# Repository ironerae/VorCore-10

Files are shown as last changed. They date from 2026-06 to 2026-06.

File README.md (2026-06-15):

VorCore 10 Custom CoreXY Gantry Mounts

# VorCore 10: Custom CoreXY Gantry Mounts

VorCore 10 is a custom-designed, open-source CoreXY kinematic mounting system. It bridges the gap between the heavy-duty front-motor layout of the SolidCore and the clean, stacked belt routing made popular by Voron designs.

Optimized and tested for a large, rigid 1000x1000x500mm build volume, this system is built entirely around wider 10mm GT2 belts to handle aggressive accelerations without stretching or skipping.

## Design Lineage & Features

- **SolidCore Inspiration:** X and Y stepper motors are front-mounted, pushing the center of gravity forward and freeing up space at the rear of the machine.
- **Voron-Style Routing:** The belts route across the front of the X-axis extrusion in a stacked configuration, ensuring clean, parallel belt paths rather than looping behind the starting belt.
- **Heavy-Duty 10mm Belts:** Dimensioned strictly for 10mm GT2 belts and matching hardware to eliminate belt stretch on high-speed setups.

## The Kinematic System & Belt Routing

The VorCore 10 system utilizes standard CoreXY kinematics for its belt routing, making it familiar and straightforward to configure. The mounting system consists of four purpose-built modules designed for easy printing, assembly, and maintenance. _(Note: The Front, Center, and Back modules are required in pairs—one set for the left gantry and one set for the right.)_

CoreXY-Kinematics

1. **Front (Motor Mount):** Rigidly holds the NEMA 17 stepper motors in the front corners.
2. **Center (Extrusion Clamp):** Securely grips the X-axis extrusion and maintains perfect alignment for the front-stacked belt path.
3. **Back (Idler Mount):** Houses the rear idler pulleys to return the belts through the kinematic path.
4. **Print Head Belt Adapter:** The crucial anchoring point that cleanly terminates the 10mm stacked belts at the toolhead, ensuring perfect parallel alignment with the X-axis.

## Bill of Materials (BOM)

Below is the total hardware required to build the complete X/Y gantry system.

**Front (Motor Mounts - Left & Right Pair)**

- 12x M3x8 bolts (6 per side)
- 2x 10mm Motor Pulley (1 per side)

**Center (Extrusion Clamps - Left & Right Pair)**

- 4x M5x8 bolts (2 per side, for attaching to 20mm V-Slot Gantry Plate)
- 4x M5x25 bolts (2 per side, for the idlers)
- 4x M3x8 bolts (2 per side, for attaching to the extrusion)
- 2x 10mm GT2 Idlers with teeth (1 per side)
- 2x 10mm GT2 Idlers without teeth / smooth (1 per side)

**Back (Idler Mounts - Left & Right Pair)**

- 2x M5x40 bolts (1 per side, for the idler stack)
- 4x 10mm GT2 Idlers with teeth (2 per side)

**Print Head Belt Adapter (Single Unit)**

- 2x M5x8 bolts (for attaching to 20mm V-Slot Gantry Plate)
- _Note: The adapter includes extra bolt slots for mounting a BLTouch, or other custom toolhead accessories. Feel free to explore and modify!_

## CAD & Source Files

This project was designed entirely in Onshape. To make modifications, adjust for different extrusion profiles, or tweak hole tolerances, you can copy the public workspace directly:

- **[Link to Public Onshape Document](https://cad.onshape.com/documents/c695cb2f7fbb45d5485f2701/w/7bdce7ef937412e146022feb/e/c0170e9e5d0967ed7b441d22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)**

For users who just want to print and assemble, the exported STLs and high-resolution STEP files are included in the `files` directory.

## Recommended Print Settings

To ensure the mounts have the rigidity required to handle 10mm belt tension and high accelerations, please follow these minimum printing guidelines:

- **Material:** ABS, ASA, or PC (PETG can work, but avoid PLA as it will creep under belt tension and motor heat)
- **Wall Loops / Perimeters:** 4
- **Top / Bottom Shells:** 5
- **Infill:** 40% (Grid, Gyroid, or Honeycomb)
- **Layer Height:** 0.2mm

## License

This project is fully open-source. Feel free to download, modify, remix, and share your own upgrades!

---

_VorCore 10 by ironerae_

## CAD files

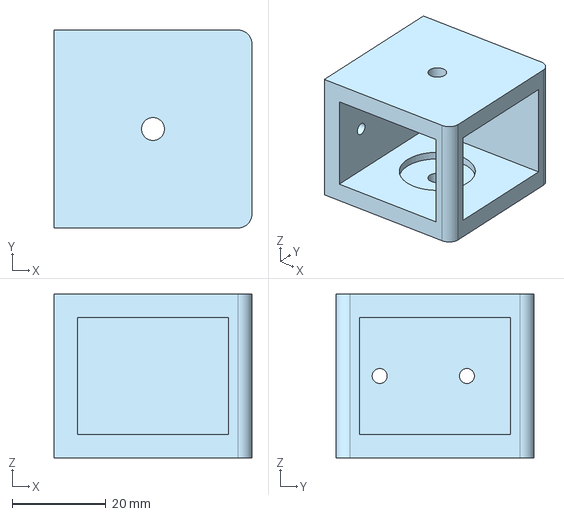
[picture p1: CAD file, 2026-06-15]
files/step/Back (Idler Mount).step
42.3 x 42.3 x 35.0 mm

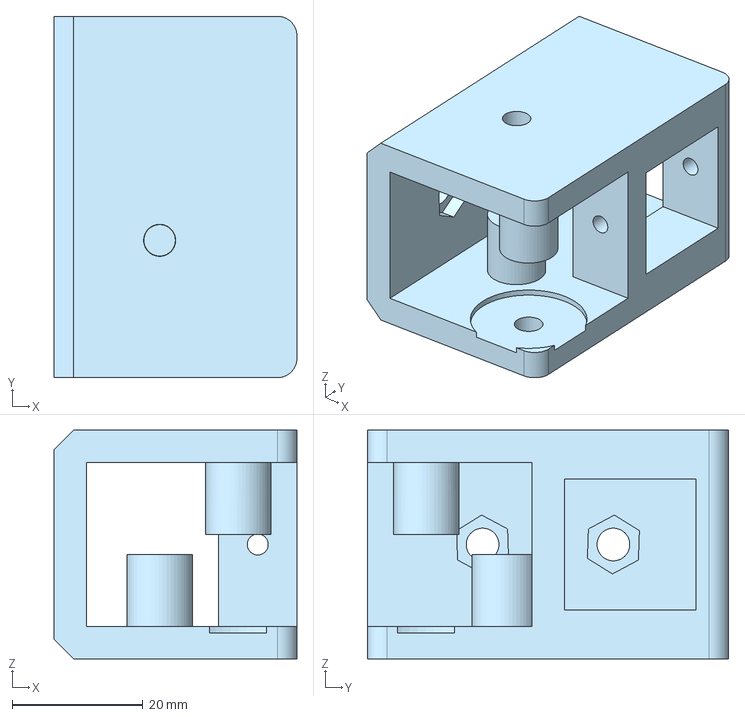
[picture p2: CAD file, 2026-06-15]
files/step/Center (Extrusion Clamp).step
37.1 x 55.2 x 35.0 mm

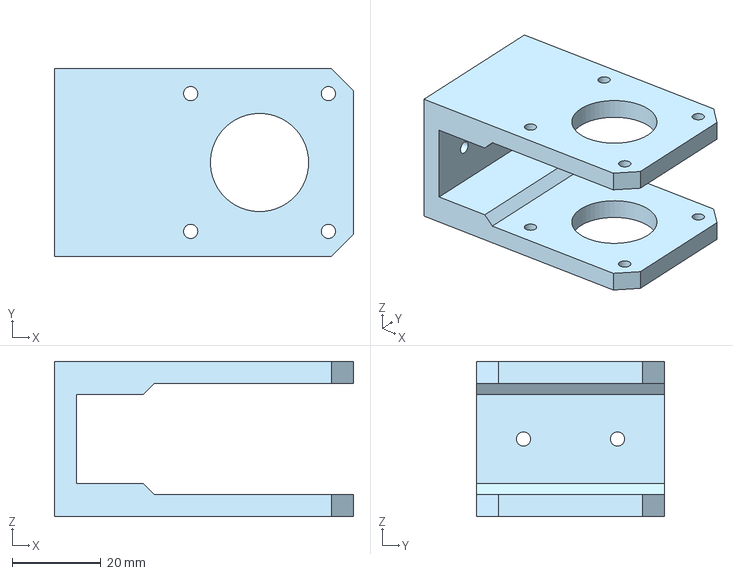
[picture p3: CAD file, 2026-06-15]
files/step/Front (Motor Mount).step
67.3 x 42.3 x 35.0 mm

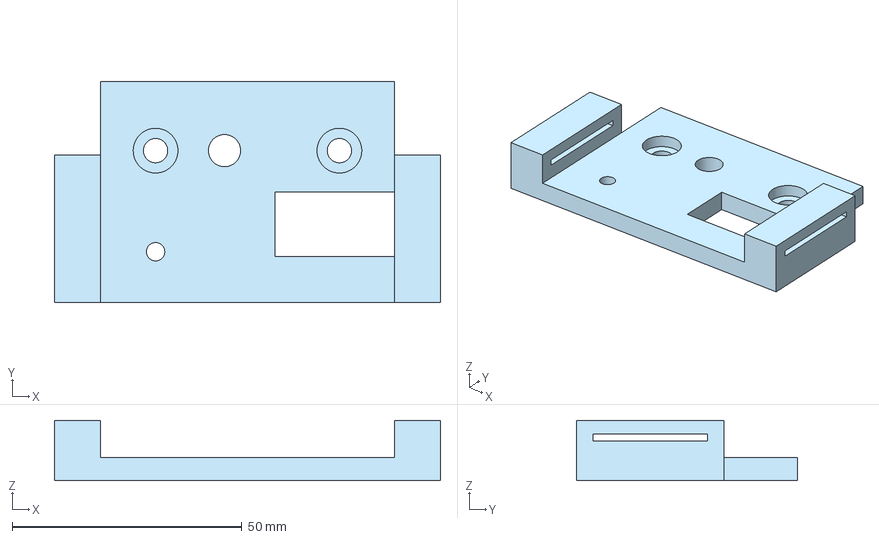
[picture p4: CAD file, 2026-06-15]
files/step/Print Head Belt Adapter.step
84.0 x 48.0 x 13.2 mm

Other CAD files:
files/stl/Back (Idler Mount).stl
files/stl/Center (Extrusion Clamp).stl
files/stl/Front (Motor Mount).stl
files/stl/Print Head Belt Adapter.stl

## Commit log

2026-06-15 Revise README for VorCore 10 project details
    Updated README.md to include detailed project description, features, BOM, CAD files, and recommended print settings for VorCore 10.
2026-06-15 added step and stl files
    [Back (Idler Mount).step, Back (Idler Mount).stl, Center (Extrusion Clamp).step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]
